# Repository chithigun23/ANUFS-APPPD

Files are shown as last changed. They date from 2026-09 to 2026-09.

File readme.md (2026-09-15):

# ANUFS APPPD

<p align="center">
  ANUFS APPPD system architecture - animated diagram of power, pedal/throttle sensing, shutdown control and CAN flow
</p>

Accelerator pedal position (APPS) and throttle position (TPS) sensor interface for the ANUFS vehicle, with dual-redundant sensing, ignition/electronic-throttle-body kill-switch control, and CAN reporting. A single 8-pin harness connector carries power in, both raw sensor pairs, and the two kill lines out.

## Architecture

- **Power** - the LV battery feed arrives on the shared harness connector, passes through an ideal-diode PFET (Zener-biased) for reverse-polarity/surge protection, and feeds `U6` (LMR33610), which bucks it to 5V. That 5V is diode-ORed with USB-C VBUS onto a single fused node that only ever feeds `U1` (AP2112K-3.3) - the **+3.3V rail is the only supply that leaves the power stage**, reaching the MCU, CAN transceiver, both op-amps and the status LED.
- **Pedal & throttle sensing** - the harness carries two raw accelerator-pedal signals (APPS1/APPS2) and two raw throttle-position signals (TPS1/TPS2), each individually clamped by an automotive `AQ1005-01ETG` TVS array. `U5` and `U7` (`TLV9062` dual op-amps) buffer them with unity gain straight into the MCU's ADC inputs.
- **Compute** - `U2`, an STM32F072CBTx (Cortex-M0), is the hub, clocked from a 24MHz crystal (`Y1`).
- **Shutdown control** - the MCU drives two low-side MOSFETs (`Q1` for ignition, `Q2` for electronic throttle body) that pull the corresponding harness line to ground to trip the external kill relay. Each line has an inline LED (`D3`, `D5`) that lights while its kill switch is active, so the cut state is visible without a laptop. A separate GPIO-driven LED (`LED1`) gives a general board heartbeat/fault indication.
- **Comms** - a `TCAN337` transceiver (`U4`) puts pedal/throttle status and kill-line faults on the vehicle CAN bus via `J4`.
- **Debug & USB** - USB-C (`J5`, ESD-protected by `U3`) for bench debug/firmware and D+/D- to the MCU; `J1` (Conn_SWD) for programming.

The diagram above is a live SVG: dashed lines show active power/signal paths, and the small dots trace the flow through each domain (open `assets/architecture.svg` directly if your viewer doesn't animate it).

## Repo contents

- [KiCad project](apppd.kicad_pro)
- [Schematic](apppd.kicad_sch)
- [PCB layout](apppd.kicad_pcb)
- [Bill of materials](APPPD_DigiKey_BOM.xlsx)

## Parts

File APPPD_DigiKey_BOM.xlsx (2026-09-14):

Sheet: BOM
# | Reference(s) | Qty | Value | Package / Footprint | Manufacturer | Manufacturer Part Number (MPN) | DigiKey Part Number | Purchasing spec / action | Notes
1 | C1,C9,C15,C24 | 4 | 10uF | C_0402_1005Metric_Pad0.74x0.62mm_HandSolder |  |  |  | Select exact supplier part matching value and footprint.
2 | C2,C3,C11,C17,C23 | 5 | 1uF | C_0402_1005Metric_Pad0.74x0.62mm_HandSolder |  |  |  | Select exact supplier part matching value and footprint.
3 | C5-C8,C10,C12,C18,C26-C31 | 13 | 100nF | C_0402_1005Metric_Pad0.74x0.62mm_HandSolder |  |  |  | Select exact supplier part matching value and footprint.
4 | C13,C14 | 2 | 8pF | C_0402_1005Metric_Pad0.74x0.62mm_HandSolder |  |  |  | Select exact supplier part matching value and footprint.
5 | C16 | 1 | 220nF | C_0402_1005Metric_Pad0.74x0.62mm_HandSolder |  |  |  | Select exact supplier part matching value and footprint.
6 | C19,C20 | 2 | 22uF | C_0402_1005Metric_Pad0.74x0.62mm_HandSolder |  |  |  | Select exact supplier part matching value and footprint.
7 | D1 | 1 | BZT52-C15S-AU_R1_000A1 | D_SOD-323_HandSoldering |  | BZT52-C15S-AU_R1_000A1 |  | Match package and ordering suffix. | Part identifier from schematic value; verify exact ordering code.
8 | D2 | 1 | SMF16A | SMF16A | Littelfuse | SMF16A |  | Match package and ordering suffix. | LCSC: C207257
9 | D3,D5 | 2 | LED | AP2012EC |  |  |  | Select exact supplier part matching value and footprint.
10 | D4,D6,D9,D12 | 4 | AQ1005-01ETG | AQ1005-01ETG | Littelfuse | AQ1005-01ETG |  | Match package and ordering suffix.
11 | D10,D11 | 2 | PMEG2010BER | Nexperia_CFP3_SOD-123W |  | PMEG2010BER |  | Match package and ordering suffix. | Part identifier from schematic value; verify exact ordering code.
12 | D13,D14 | 2 | PMEG6010ER | Nexperia_CFP3_SOD-123W |  | PMEG6010ER |  | Match package and ordering suffix. | Part identifier from schematic value; verify exact ordering code.
13 | F1 | 1 | 300mA Polyfuse | Fuse_0805_2012Metric_Pad1.15x1.40mm_HandSolder |  |  |  | Select exact supplier part matching value and footprint.
14 | FB1 | 1 | FerriteBead | C_0603_1608Metric_Pad1.08x0.95mm_HandSolder |  |  |  | Select exact supplier part matching value and footprint.
15 | J1 | 1 | Conn_SWD | PinHeader_1x04_P2.54mm_Vertical |  |  |  | Select exact supplier part matching value and footprint.
16 | J2 | 1 | APPPD Connector | MOLEX_430450800 |  |  |  | Select exact supplier part matching value and footprint.
17 | J4 | 1 | 2601-1102 | WAGO-2601-1102 |  |  |  | Select exact supplier part matching value and footprint.
18 | J5 | 1 | USB_C_Receptacle_USB2.0_16P | USB-C-SMD_TYPE-C-16PIN-2MD-073 |  |  |  | Select exact supplier part matching value and footprint. | LCSC: C2765186
19 | L1 | 1 | 8.2uH, 86m | L_Vishay_IHLP-1616 |  |  |  | Select exact supplier part matching value and footprint.
20 | LED1 | 1 | XL-2012SURUGC | XL-2012SURUGC | XINGLIGHT(成兴光) | XL-2012SURUGC |  | Match package and ordering suffix. | LCSC: C965845
21 | Q1,Q2 | 2 | AO3400A | SOT-23 | Alpha & Omega | AO3400A |  | Match package and ordering suffix.
22 | Q3 | 1 | PMV100EPA | SOT-23 |  | PMV100EPA |  | Match package and ordering suffix. | Part identifier from schematic value; verify exact ordering code.
23 | R1,R4-R6 | 4 | 10k | R_0402_1005Metric_Pad0.72x0.64mm_HandSolder |  |  |  | Select exact supplier part matching value and footprint.
24 | R2,R3 | 2 | 5.1k | R_0402_1005Metric_Pad0.72x0.64mm_HandSolder |  |  |  | Select exact supplier part matching value and footprint.
25 | R7,R14,R19,R26-R28,R33 | 7 | 150 | R_0402_1005Metric_Pad0.72x0.64mm_HandSolder |  |  |  | Select exact supplier part matching value and footprint.
26 | R8 | 1 | 10K | R_0402_1005Metric_Pad0.72x0.64mm_HandSolder |  |  |  | Select exact supplier part matching value and footprint.
27 | R9-R11,R15,R29-R32 | 8 | 100k | R_0402_1005Metric_Pad0.72x0.64mm_HandSolder |  |  |  | Select exact supplier part matching value and footprint.
28 | R12 | 1 | 24.9k | R_0402_1005Metric_Pad0.72x0.64mm_HandSolder |  |  |  | Select exact supplier part matching value and footprint.
29 | R20 | 1 | 470 | R_0402_1005Metric_Pad0.72x0.64mm_HandSolder |  |  |  | Select exact supplier part matching value and footprint.
30 | R21,R22 | 2 | 1k | R_0402_1005Metric_Pad0.72x0.64mm_HandSolder |  |  |  | Select exact supplier part matching value and footprint.
31 | R38-R41 | 4 | 150k | R_0402_1005Metric_Pad0.72x0.64mm_HandSolder |  |  |  | Select exact supplier part matching value and footprint.
32 | SW1 | 1 | NRST | SW-SMD_L3.9-W3.0-P4.45 | XUNPU(讯普) | TS-1088-AR02016 |  | Match package and ordering suffix. | LCSC: C720477
33 | SW2 | 1 | BOOT0 | SW-SMD_L3.9-W3.0-P4.45 | XUNPU(讯普) | TS-1088-AR02016 |  | Match package and ordering suffix. | LCSC: C720477
34 | TP1 | 1 | TPS1 | TestPoint_Keystone_5000-5004_Miniature |  |  |  | Optional physical test point; select matching footprint.
35 | TP2 | 1 | TPS2 | TestPoint_Keystone_5000-5004_Miniature |  |  |  | Optional physical test point; select matching footprint.
36 | TP3,TP4 | 2 | BPS | TestPoint_Keystone_5000-5004_Miniature |  |  |  | Optional physical test point; select matching footprint.
37 | TP5 | 1 | CAN+ | TestPoint_THTPad_D2.0mm_Drill1.0mm |  |  |  | Optional physical test point; select matching footprint.
38 | TP6 | 1 | CAN- | TestPoint_THTPad_D2.0mm_Drill1.0mm |  |  |  | Optional physical test point; select matching footprint.
39 | TP7 | 1 | +3V3 | TestPoint_THTPad_D2.0mm_Drill1.0mm |  |  |  | Optional physical test point; select matching footprint.
40 | TP8 | 1 | VIN_LDO | TestPoint_THTPad_D2.0mm_Drill1.0mm |  |  |  | Optional physical test point; select matching footprint.
41 | TP9 | 1 | GND | TestPoint_THTPad_D2.0mm_Drill1.0mm |  |  |  | Optional physical test point; select matching footprint.
42 | U1 | 1 | AP2112K-3.3 | SOT-23-5_HandSoldering |  | AP2112K-3.3 |  | Match package and ordering suffix. | Part identifier from schematic value; verify exact ordering code.
43 | U2 | 1 | STM32F072CBTx | LQFP-48_7x7mm_P0.5mm |  |  |  | Select exact supplier part matching value and footprint.
44 | U3 | 1 | USBLC6-2SC6 | SOT-23-6 |  | USBLC6-2SC6 |  | Match package and ordering suffix. | Part identifier from schematic value; verify exact ordering code.
45 | U4 | 1 | TCAN337 | SOIC-8_3.9x4.9mm_P1.27mm |  | TCAN337 |  | Match package and ordering suffix. | Part identifier from schematic value; verify exact ordering code.
46 | U5,U7 | 2 | TLV9062xD | SOIC-8_3.9x4.9mm_P1.27mm |  |  |  | Select exact supplier part matching value and footprint.
47 | U6 | 1 | LMR33610ADDAR | LMR33610_HSOP8_SolidGND |  | LMR33610ADDAR |  | Match package and ordering suffix. | Part identifier from schematic value; verify exact ordering code.
48 | Y1 | 1 | ABM8AIG-24.000MHz-8-2Z-T | ABM8AIG-24.000MHZ-8-2Z-T | Abracon | ABM8AIG-24.000MHz-8-2Z-T |  | Match package and ordering suffix. | Part identifier from schematic value; verify exact ordering code.
 | TOTAL PLACEMENTS | 99

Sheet: Cautions
Item | Severity | What it is | What to do before / when ordering
Supplier selection | TO COMPLETE | Rows without an exact MPN require part selection. | Use the value, footprint and listed specifications. Blank DigiKey numbers have not been sourced.
DigiKey Upload | SCOPE | Only explicit schematic MPNs and non-inferred existing BOM MPNs are included. | Resolve rows with missing or inferred part numbers on the BOM before adding them to an order.
Quantity basis | INFO | 99 BOM-included board items; one board. | Excludes: H1, H2, H3, H4. Optional test points and bare wire pads may not require purchased parts.
Source | INFO | Current apppd.kicad_pcb and matching schematic, 2026-09-15. | Quantities and footprints use the PCB. Part metadata uses the schematic.

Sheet: DigiKey Upload
Manufacturer Part Number | Quantity | Customer Reference
SMF16A | 1 | D2
AQ1005-01ETG | 4 | D4,D6,D9,D12
XL-2012SURUGC | 1 | LED1
TS-1088-AR02016 | 2 | SW1,SW2
Only source-specified MPNs are listed. Complete missing or inferred part numbers on the BOM before ordering.

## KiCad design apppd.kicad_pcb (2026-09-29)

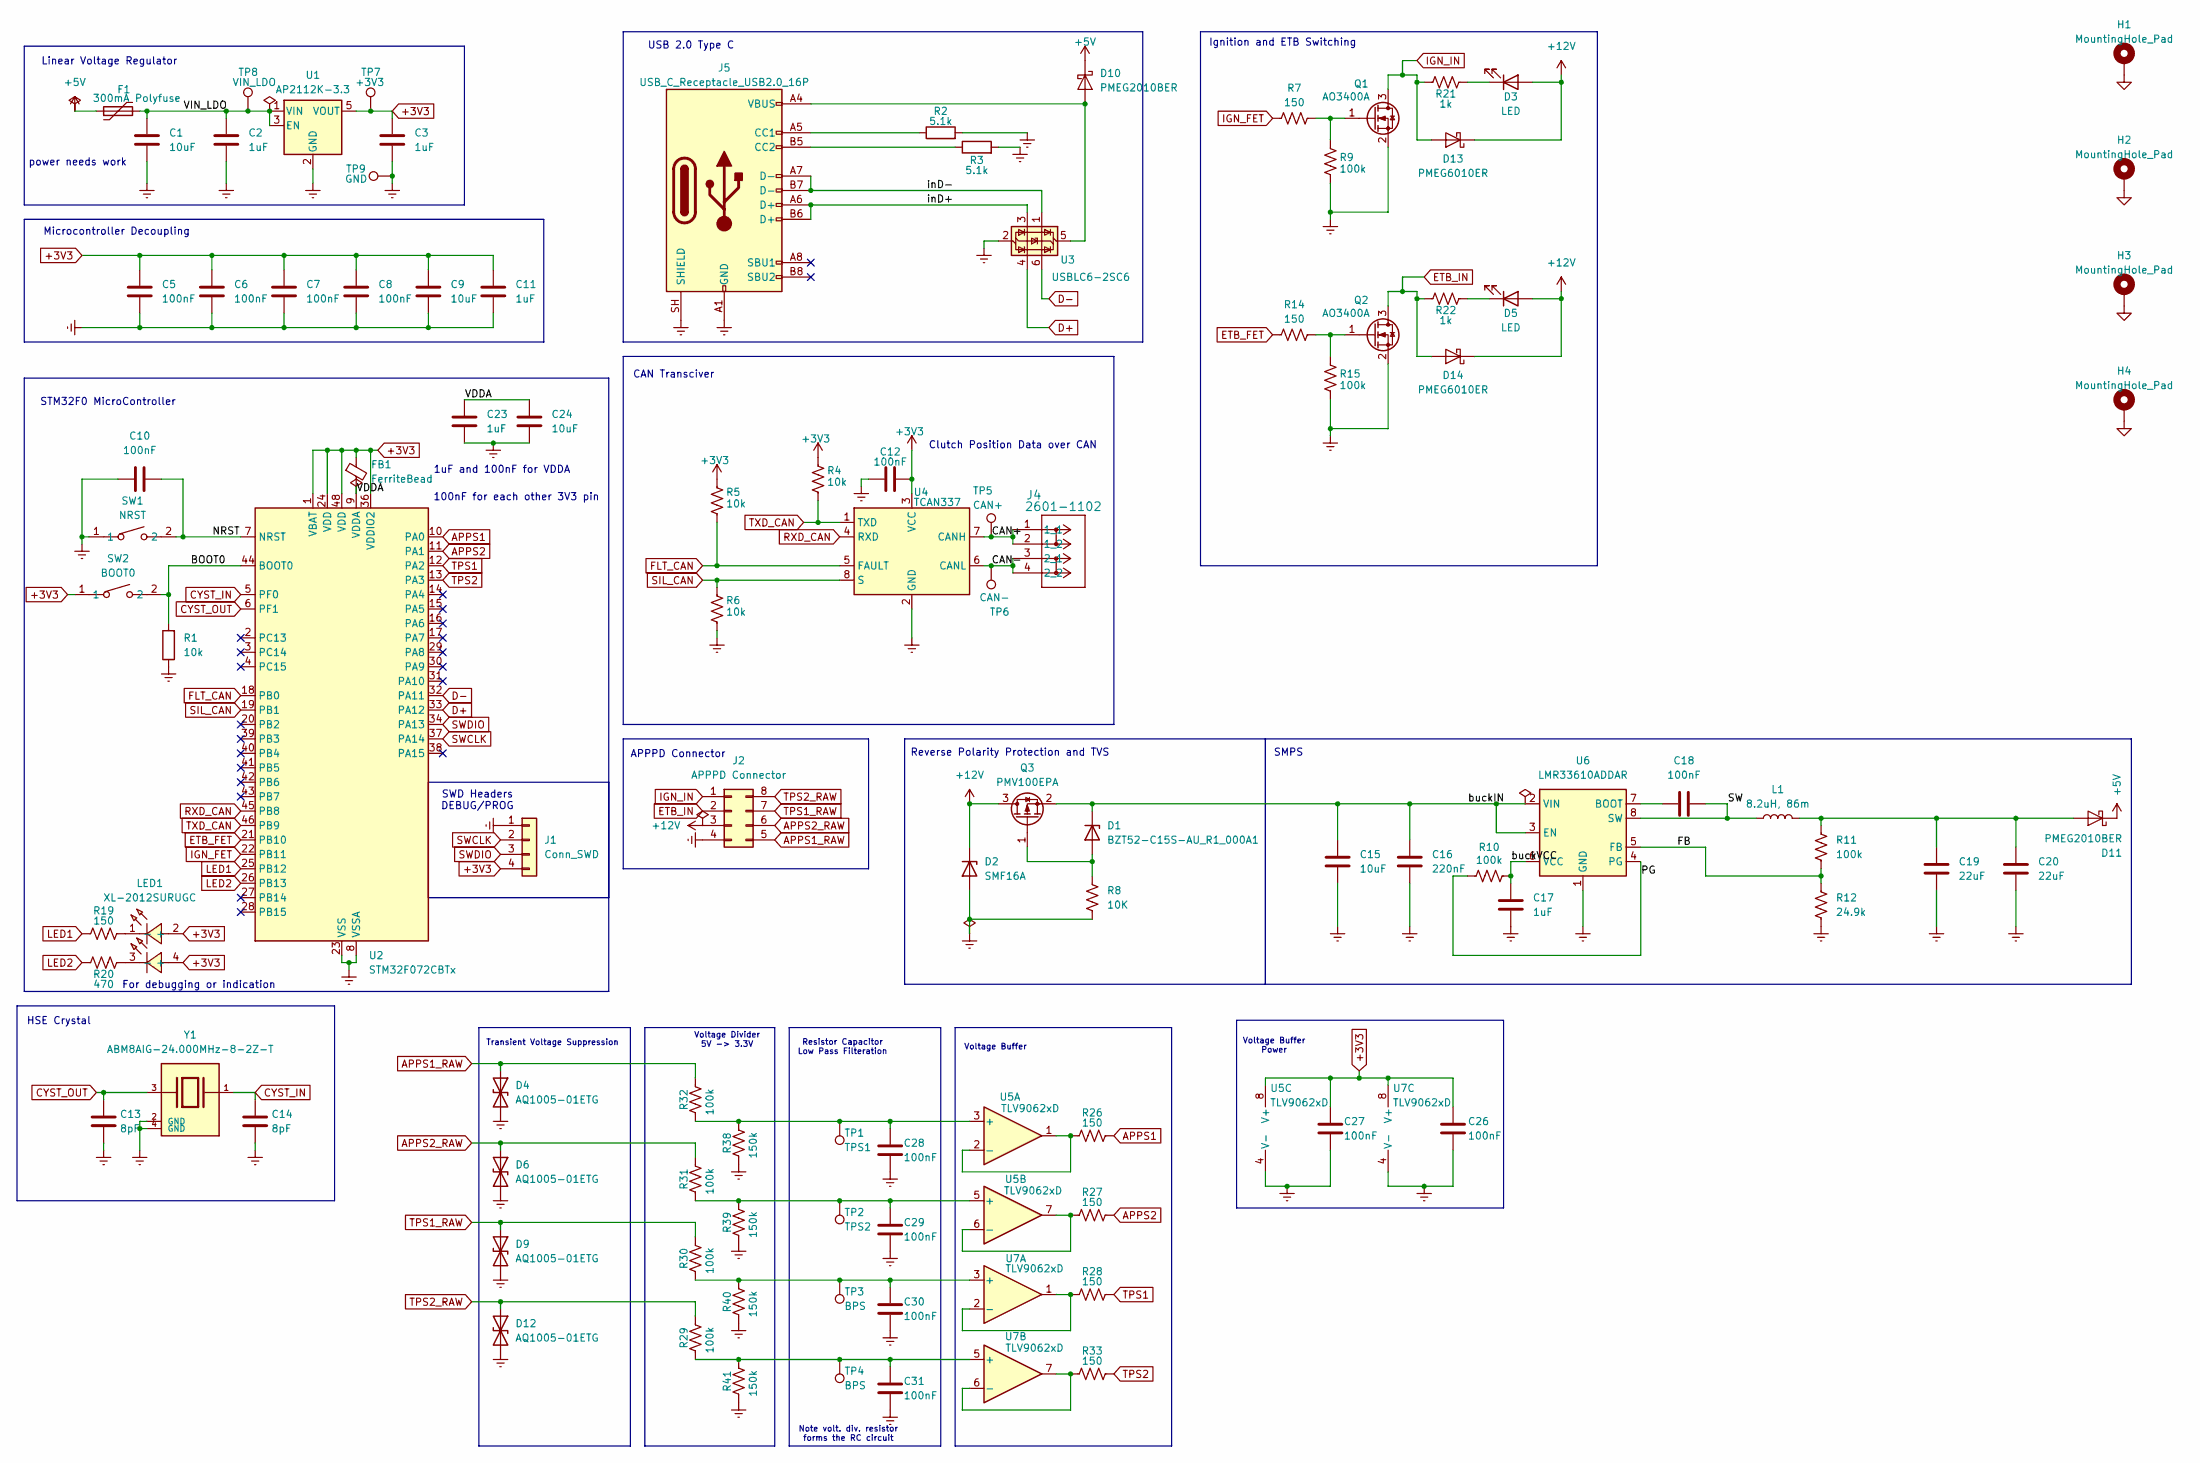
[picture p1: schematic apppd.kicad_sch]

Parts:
C1, C9, C15, C24: 10uF; C_0402_1005Metric_Pad0.74x0.62mm_HandSolder
C2, C3, C11, C17, C23: 1uF; C_0402_1005Metric_Pad0.74x0.62mm_HandSolder
C5, C6, C7, C8, C10, C12, C18, C26, C27, C28, C29, C30, C31: 100nF; C_0402_1005Metric_Pad0.74x0.62mm_HandSolder
C13, C14: 8pF; C_0402_1005Metric_Pad0.74x0.62mm_HandSolder
C16: 220nF; C_0402_1005Metric_Pad0.74x0.62mm_HandSolder
C19, C20: 22uF; C_0402_1005Metric_Pad0.74x0.62mm_HandSolder
D1: BZT52-C15S-AU_R1_000A1; D_SOD-323_HandSoldering
D2: SMF16A; MPN SMF16A; LCSC Part C207257
D3, D5: LED; AP2012EC
D4, D6, D9, D12: AQ1005-01ETG; MPN AQ1005-01ETG
D10, D11: PMEG2010BER; Nexperia_CFP3_SOD-123W
D13, D14: PMEG6010ER; Nexperia_CFP3_SOD-123W
F1: 300mA Polyfuse; Fuse_0805_2012Metric_Pad1.15x1.40mm_HandSolder
FB1: FerriteBead; C_0603_1608Metric_Pad1.08x0.95mm_HandSolder
H1, H2, H3, H4: MountingHole_Pad
J1: Conn_SWD; PinHeader_1x04_P2.54mm_Vertical
J2: APPPD Connector; MOLEX_430450800
J4: 2601-1102; WAGO-2601-1102
J5: USB_C_Receptacle_USB2.0_16P; USB-C-SMD_TYPE-C-16PIN-2MD-073
L1: 8.2uH, 86m; L_Vishay_IHLP-2525
LED1: XL-2012SURUGC; MPN XL-2012SURUGC; LCSC Part C965845
Q1, Q2: AO3400A; SOT-23
Q3: PMV100EPA; SOT-23
R1, R4, R5, R6: 10k; R_0402_1005Metric_Pad0.72x0.64mm_HandSolder
R2, R3: 5.1k; R_0402_1005Metric_Pad0.72x0.64mm_HandSolder
R7, R14, R19, R26, R27, R28, R33: 150; R_0402_1005Metric_Pad0.72x0.64mm_HandSolder
R8: 10K; R_0402_1005Metric_Pad0.72x0.64mm_HandSolder
R9, R10, R11, R15, R29, R30, R31, R32: 100k; R_0402_1005Metric_Pad0.72x0.64mm_HandSolder
R12: 24.9k; R_0402_1005Metric_Pad0.72x0.64mm_HandSolder
R20: 470; R_0402_1005Metric_Pad0.72x0.64mm_HandSolder
R21, R22: 1k; R_0402_1005Metric_Pad0.72x0.64mm_HandSolder
R38, R39, R40, R41: 150k; R_0402_1005Metric_Pad0.72x0.64mm_HandSolder
SW1: NRST; SW-SMD_L3.9-W3.0-P4.45; MPN TS-1088-AR02016; LCSC Part C720477
SW2: BOOT0; SW-SMD_L3.9-W3.0-P4.45; MPN TS-1088-AR02016; LCSC Part C720477
TP1: TPS1; TestPoint_Keystone_5000-5004_Miniature
TP2: TPS2; TestPoint_Keystone_5000-5004_Miniature
TP3, TP4: BPS; TestPoint_Keystone_5000-5004_Miniature
TP5: CAN+; TestPoint_THTPad_D2.0mm_Drill1.0mm
TP6: CAN-; TestPoint_THTPad_D2.0mm_Drill1.0mm
TP7: +3V3; TestPoint_THTPad_D2.0mm_Drill1.0mm
TP8: VIN_LDO; TestPoint_THTPad_D2.0mm_Drill1.0mm
TP9: GND; TestPoint_THTPad_D2.0mm_Drill1.0mm
U1: AP2112K-3.3; SOT-23-5_HandSoldering
U2: STM32F072CBTx; LQFP-48_7x7mm_P0.5mm
U3: USBLC6-2SC6; SOT-23-6
U4: TCAN337; SOIC-8_3.9x4.9mm_P1.27mm
U5, U7: TLV9062xD; SOIC-8_3.9x4.9mm_P1.27mm
U6: LMR33610ADDAR; LMR33610_HSOP8_SolidGND
Y1: ABM8AIG-24.000MHz-8-2Z-T; ABM8AIG-24.000MHZ-8-2Z-T; PARTREV 43629

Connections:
+3V3: C3.1, C5.2, C6.2, C7.2, C8.2, C9.2, C11.1, C12.2, C26.2, C27.2, FB1.1, J1.4, LED1.2 (+), LED1.4 (+), R4.1, R5.1, SW2.1, TP7.1 (1_1), U1.5 (VOUT), U2.1 (VBAT), U2.24 (VDD), U2.36 (VDDIO2), U2.48 (VDD), U4.3 (VCC), U5.8 (V+), U7.8 (V+)
+5V: D10.1 (K), D11.1 (K), F1.1
+12V: D2.1 (K), D3.2 (A), D5.2 (A), D13.1 (K), D14.1 (K), J2.3, Q3.3 (D)
/BOOT0: R1.2, SW2.2, U2.44 (BOOT0)
/CAN+: J4.1 (1_1), J4.2 (1_2), TP5.1 (1_1), U4.7 (CANH)
/CAN-: J4.3 (2_1), J4.4 (2_2), TP6.1 (1_1), U4.6 (CANL)
/FB: R11.2, R12.1, U6.5 (FB)
/NRST: C10.2, SW1.2, U2.7 (NRST)
/PG: R10.1, U6.4 (PG)
/SW: C18.2, L1.1, U6.8 (SW)
/VDDA: C23.1, C24.2, FB1.2, U2.9 (VDDA)
/VIN_LDO: C1.2, C2.1, F1.2, TP8.1 (1_1), U1.1 (VIN), U1.3 (EN)
/buckIN: C15.1, C16.1, D1.1 (K), Q3.2 (S), U6.2 (VIN), U6.3 (EN)
/buckVCC: C17.1, R10.2, U6.6 (VCC)
/inD+: J5.A6 (D+), J5.B6 (D+), U3.3 (I/O2)
/inD-: J5.A7 (D-), J5.B7 (D-), U3.1 (I/O1)
APPS1: R26.2, U2.10 (PA0)
APPS1_RAW: D4.1 (A1), J2.5, R32.2
APPS2: R27.2, U2.11 (PA1)
APPS2_RAW: D6.1 (A1), J2.6, R31.2
CYST_IN: C14.1, U2.5 (PF0), Y1.1
CYST_OUT: C13.1, U2.6 (PF1), Y1.3
D+: U2.33 (PA12), U3.4 (I/O2)
D-: U2.32 (PA11), U3.6 (I/O1)
ETB_FET: R14.1, U2.21 (PB10)
ETB_IN: D14.2 (A), J2.2, Q2.3 (D), R22.1
FLT_CAN: R5.2, U2.18 (PB0), U4.5 (FAULT)
GND: C1.1, C2.2, C3.2, C5.1, C6.1, C7.1, C8.1, C9.1, C10.1, C11.2, C12.1, C13.2, C14.2, C15.2, C16.2, C17.2, C19.2, C20.2, C23.2, C24.1, C26.1, C27.1, C28.1, C29.1, C30.1, C31.1, D2.2 (A), D4.2 (A2), D6.2 (A2), D9.2 (A2), D12.2 (A2), H1.1 (1_1), H2.1 (1_1), H3.1 (1_1), H4.1 (1_1), J1.1, J2.4, J5.A1 (GND), J5.A12 (GND), J5.B1 (GND), J5.B12 (GND), J5.SH (SHIELD), Q1.2 (S), Q2.2 (S), R1.1, R2.2, R3.2, R6.2, R8.2, R9.1, R12.2, R15.1, R38.1, R39.1, R40.1, R41.1, SW1.1, TP9.1 (1_1), U1.2 (GND), U2.8 (VSSA), U2.23 (VSS), U2.35 (VSS), U2.47 (VSS), U3.2 (GND), U4.2 (GND), U5.4 (V-), U6.1 (GND), U6.9 (GND), U7.4 (V-), Y1.2 (GND), Y1.4 (GND)
IGN_FET: R7.1, U2.22 (PB11)
IGN_IN: D13.2 (A), J2.1, Q1.3 (D), R21.1
LED1: R19.1, U2.25 (PB12)
LED2: R20.1, U2.26 (PB13)
unnamed: D1.2 (A), Q3.1 (G), R8.1
unnamed: D3.1 (K), R21.2
unnamed: D5.1 (K), R22.2
unnamed: D10.2 (A), J5.A4 (VBUS), J5.A9 (VBUS), J5.B4 (VBUS), J5.B9 (VBUS), U3.5 (VBUS)
unnamed: C19.1, C20.1, D11.2 (A), L1.2, R11.1
unnamed: J5.A5 (CC1), R2.1
unnamed: J5.B5 (CC2), R3.1
unnamed: LED1.1 (-), R19.2
unnamed: LED1.3 (-), R20.2
unnamed: Q1.1 (G), R7.2, R9.2
unnamed: Q2.1 (G), R14.2, R15.2
unnamed: C28.2, R32.1, R38.2, TP1.1 (1_1), U5.3 (+)
unnamed: R26.1, U5.1, U5.2 (-)
unnamed: C29.2, R31.1, R39.2, TP2.1 (1_1), U5.5 (+)
unnamed: R27.1, U5.6 (-), U5.7
unnamed: C18.1, U6.7 (BOOT)
unnamed: C30.2, R30.1, R40.2, TP3.1 (1_1), U7.3 (+)
unnamed: R28.1, U7.1, U7.2 (-)
unnamed: C31.2, R29.1, R41.2, TP4.1 (1_1), U7.5 (+)
unnamed: R33.1, U7.6 (-), U7.7
RXD_CAN: U2.45 (PB8), U4.4 (RXD)
SIL_CAN: R6.1, U2.19 (PB1), U4.8 (S)
SWCLK: J1.2, U2.37 (PA14)
SWDIO: J1.3, U2.34 (PA13)
TPS1: R28.2, U2.12 (PA2)
TPS1_RAW: D9.1 (A1), J2.7, R30.2
TPS2: R33.2, U2.13 (PA3)
TPS2_RAW: D12.1 (A1), J2.8, R29.2
TXD_CAN: R4.2, U2.46 (PB9), U4.1 (TXD)

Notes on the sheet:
Note volt. div. resistor forms the RC circuit
Voltage Buffer Power
Microcontroller Decoupling
Resistor Capacitor Low Pass Filteration
100nF for each other 3V3 pin
SMPS
SWD Headers DEBUG/PROG
Linear Voltage Regulator
Voltage Divider 5V -> 3.3V
Clutch Position Data over CAN
Ignition and ETB Switching
For debugging or indication
USB 2.0 Type C
APPPD Connector
HSE Crystal
Reverse Polarity Protection and TVS
Transient Voltage Suppression
1uF and 100nF for VDDA
CAN Transciver
Voltage Buffer
STM32F0 MicroController
power needs work

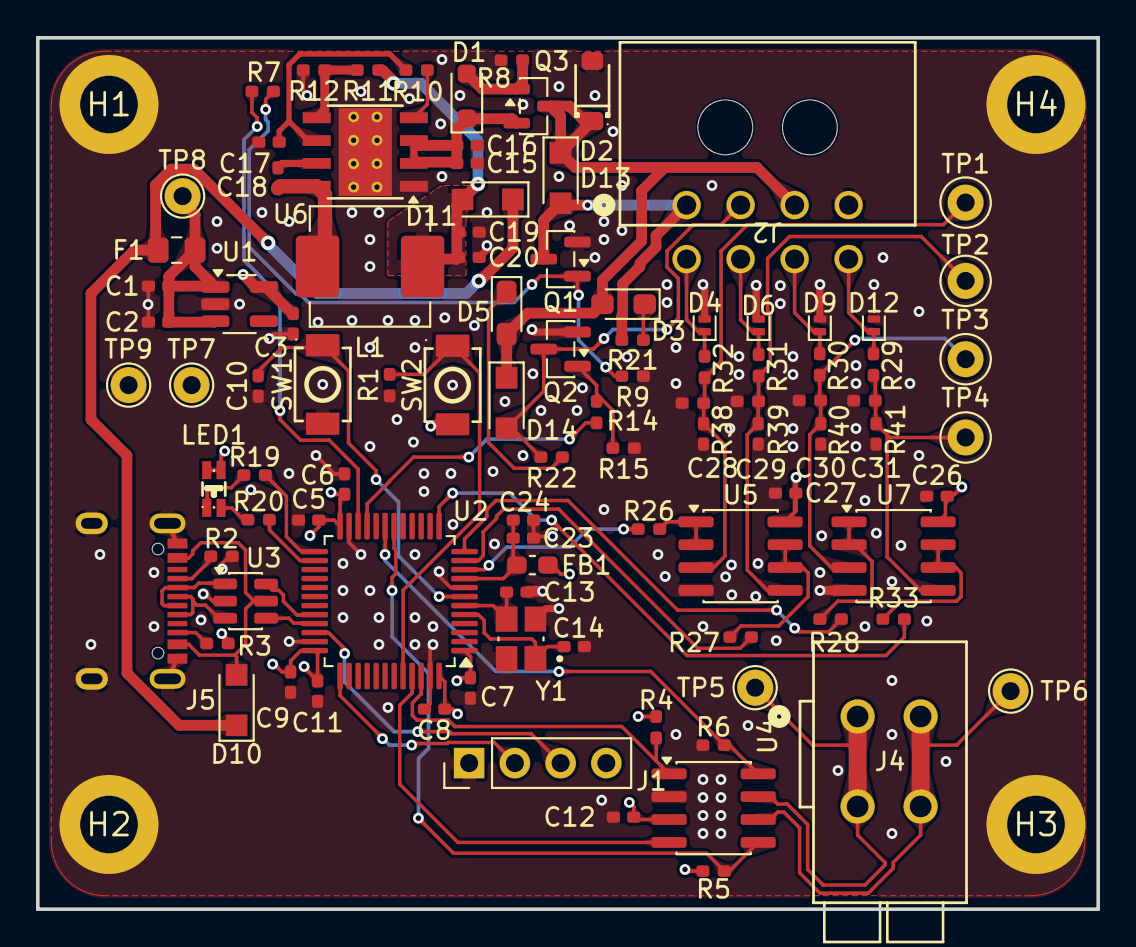
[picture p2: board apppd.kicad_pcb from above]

Board: 4 copper layers, 58.9 x 48.4 mm, 103 parts (0 on the bottom side), 61 nets.

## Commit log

2026-09-04 Added basic components from GPS
    [apppd.kicad_sch]
2026-09-05 Added buck converter, FETs and indication LEDs. Near complete
    [apppd.kicad_pcb, apppd.kicad_sch]
2026-09-07 Voltage shift for apps and tps sensors, 3v3 compatability
    [apppd.kicad_pcb, apppd.kicad_sch]
2026-09-07 Fixed ground and small changes
    [apppd.kicad_pcb, apppd.kicad_sch]
2026-09-08 Fixed GND net
    [apppd.kicad_sch]
2026-09-08 layout progress
    [apppd.kicad_pcb]
2026-09-10 Layout progress, still need to do buck
    [apppd.kicad_pcb, apppd.kicad_sch]
2026-09-13 Fixed USB-C connector footprint
2026-09-13 Fixed ERC power warnings, AQ1005 ratings, and mounting holes
    Cleaned up ERC to 0 errors/0 warnings, fixed the AQ1005 TVS description to match the datasheet, and added the missing mounting holes to the schematic.
    [apppd.kicad_pcb, apppd.kicad_sch]
2026-09-13 Removed the tight body-edge silk marks on 0402 R/C footprints
    They sat closer to the pads than JLCPCB's 0.15mm silk clearance rule allows, causing most of the silkscreen DRC warnings. Ref-des text is untouched.
    [apppd.kicad_pcb]
2026-09-14 BOM updated and folder cleaned
    [APPPD_DigiKey_BOM.xlsx]
2026-09-16 Swapped inductor due to availability
    [apppd.kicad_pcb, apppd.kicad_sch]
2026-09-29 Add pad/via teardrops and commit JLCPCB gerbers
    - Teardrops on 321 track-to-pad/via junctions (length 0.5 x pad, max 1 mm;
    width = smaller pad dimension, max 2 mm; 30% of the gap on short
    pad-to-pad bridges; skipped on pads inside their own pour). Teardrops
    enabled on every pad and via so KiCad maintains them on later edits.
    - Tracks, vias, footprints and pours unchanged; zone-refilled DRC unchanged
    (0 errors, 0 unconnected); netlist 103/103 parts, 303/303 pad nets.
    - JLCPCB_gerbers/ regenerated (soldermask subtracted from silkscreen) and
    now tracked; only F.Cu and B.Cu differ from the previous set.
    [apppd-B_Cu.gbl, apppd-B_Mask.gbs, apppd-B_Silkscreen.gbo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]
